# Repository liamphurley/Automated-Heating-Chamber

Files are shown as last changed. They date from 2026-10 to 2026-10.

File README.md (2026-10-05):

# ESP32 Automated Heating Chamber

An ESP32-based temperature control system that monitors temperature with a **DS18B20 digital temperature sensor**, controls a **12 V heating element and cooling fan**, displays live information on an **OLED screen**, and provides a **Wi-Fi web interface** for remote temperature control and monitoring.

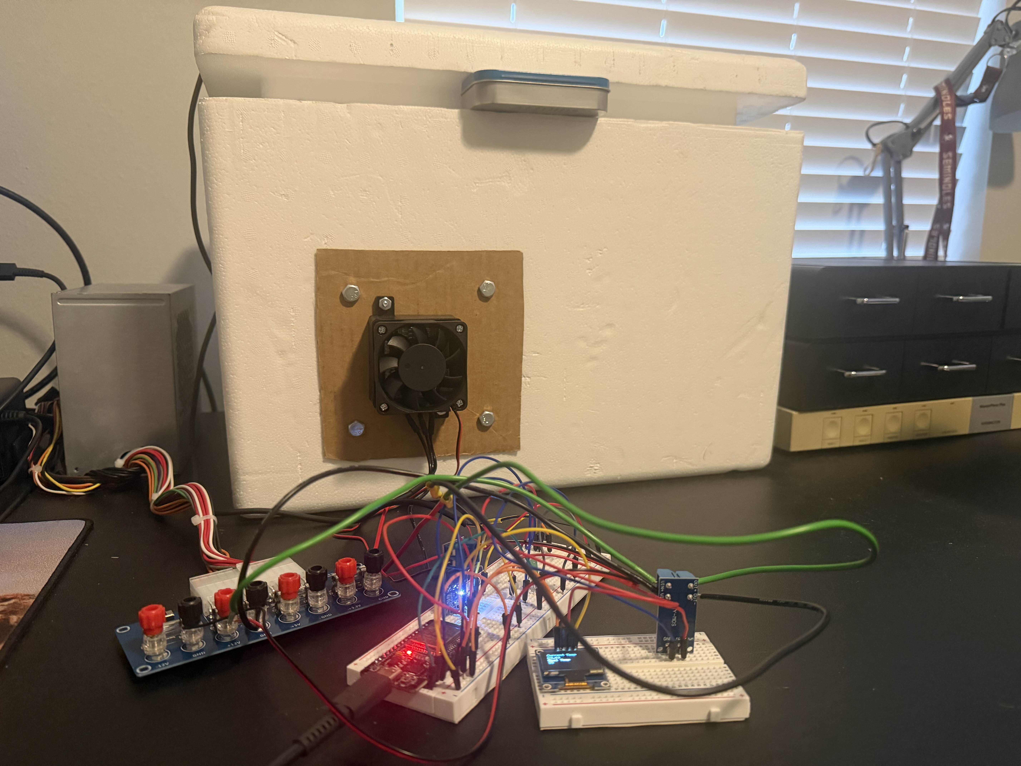
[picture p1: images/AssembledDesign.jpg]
Assembled Design


## Features

*  Real-time temperature measurement using a DS18B20
*  Automatic heating control based on a configurable target temperature
*  Cooling fan control
*  128×64 SSD1306 OLED display
*  Wi-Fi connectivity through the ESP32
*  Browser-based control interface
*  Temperature history logging
*  Text-based temperature graph accessible through the web interface
*  Stores up to 5,000 temperature records in memory
*  Records temperature and heater state over time

## Hardware

| Component | Purpose | ESP32 Pin |
| --- | --- | ---: |
| ESP32 | Main controller | — |
| DS18B20 | Temperature sensor  | GPIO 2 |
| Heating element / MOSFET | Temperature control | GPIO 5 |
| Cooling fan / MOSFET | Cooling | GPIO 19 |
| SSD1306 OLED | Local display | I²C |
| 12 V power supply | Heater/fan power | — |

> **Note:** The heater and fan should not be powered directly from ESP32 GPIO pins. A suitable MOSFET or switching module must be used to interface the ESP32 with higher-power loads.

## System Overview

The ESP32 continuously measures the temperature and compares it against the user-defined target temperature.

```text
                 ┌─────────────────┐
                 │     ESP32       │
                 │                 │
                 │ Temperature     │
                 │ Control Logic   │
                 └───────┬─────────┘
                         │
              ┌──────────┼──────────┐
              │          │          │
              ▼          ▼          ▼
         DS18B20       Heater       Fan
        Temperature    Control     Control
          Sensor       GPIO 5     GPIO 19
              │
              │
              ▼
        Temperature Data
              │
        ┌─────┴─────┐
        │           │
        ▼           ▼
    OLED Display  Web Interface
```

## The Chamber

The Chamber was assembled using a stytofoam cooler with the heating component mounted to the side. The external bracket was made with cardboard due to a previous version's 3D printed PLA bracket melting while testing. Internally a 3D printed PLA bracket is still in use. The sensor is hanging in the center of the chamber while the lid is propped open for ventilation. 

The microcontroller, MOSFET boards, and OLED are all connected using breadboards and jumper wires. In a future version it would be best to clean up this assembly but, usability is fully intact due to the webpage. The power for the design is provided by a an ATX power supply connected to a fused adapter board.

Assembled Design

## Temperature Control

The system uses a target temperature (`goalTemp`) to determine when heating should be enabled or disabled.

The default target temperature is:

```cpp
int goalTemp = 35;
```

### Heating

When the measured temperature falls more than **0.5°C below the target**, the heater is enabled.

```text
Temperature < Target - 0.5°C
            ↓
        Heater ON
```

### Cooling

When the measured temperature exceeds the target temperature:

```text
Temperature > Target
            ↓
        Heater OFF
        Fan ON
```

The control logic also uses timing intervals to prevent the heater from being switched unnecessarily frequently.

## OLED Display

The SSD1306 OLED displays:

* Current temperature
* Target temperature

Example:

```text
Current Temp
34.72

Goal Temp
35
```

The display uses the Adafruit SSD1306 and Adafruit GFX libraries.

## Wi-Fi Web Interface

The ESP32 connects to a Wi-Fi network and starts an HTTP server on port `80`.

After connecting, the ESP32 prints its local IP address to the Serial Monitor.

```text
WiFi connected!
192.168.x.x
```

The IP address can then be entered into a browser on the same network.

### Web Interface

The web interface displays:

* Current temperature
* Current target temperature
* Temperature input field
* Temperature history graph

The target temperature can be changed directly from the browser.

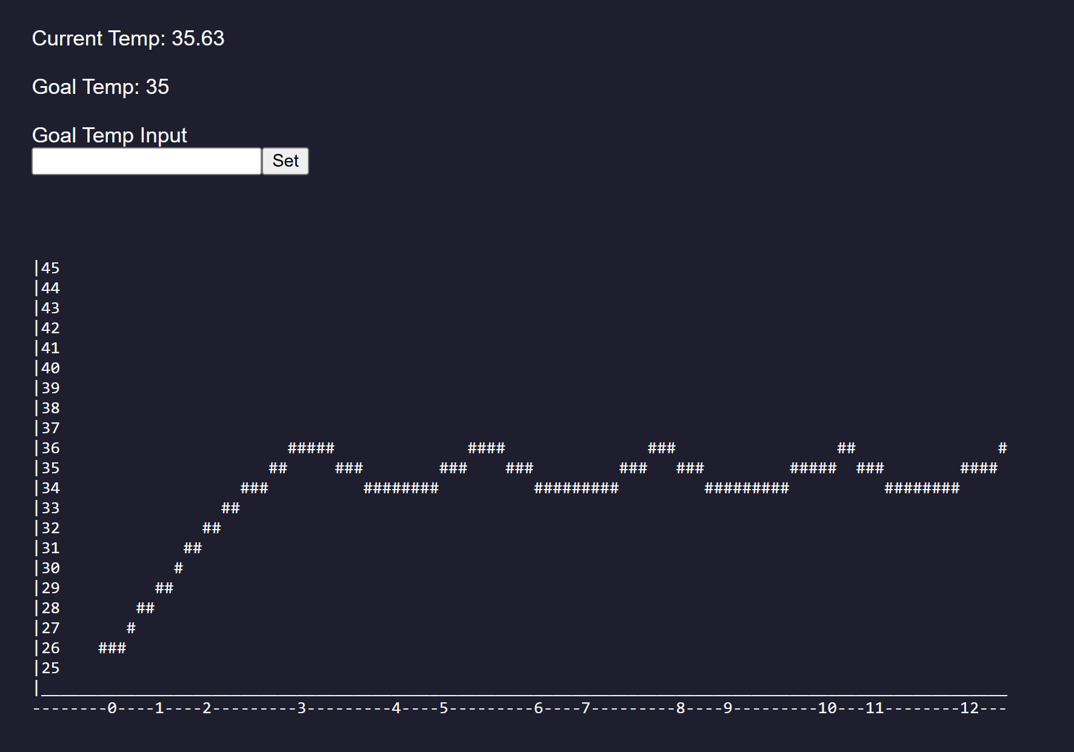
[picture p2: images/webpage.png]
Complete Webpage


## Temperature Logging

Temperature measurements are stored using the following structure:

```cpp
struct TemperatureRecord {
    unsigned long time;
    float temperature;
    bool heaterOn;
};
```

Each record contains:

| Field | Description |
| --- | --- |
| `time` | Milliseconds since ESP32 startup |
| `temperature` | Recorded temperature in °C |
| `heaterOn` | Heater state when the measurement was taken |

The system can store up to:

```cpp
#define RECORDS 5000
```

records.

Measurements are currently recorded approximately every **500 ms**.

## Temperature Graph

The `setGraph()` function converts the recorded temperature data into a text-based graph that can be displayed in the web interface.

For shorter recordings, individual temperature measurements are plotted.

For longer recordings, the data is grouped into approximately **100 sections**, with the temperature values averaged within each section. This allows the graph to represent longer recording periods without requiring thousands of characters.

The graph also includes:

* Temperature scale
* Target-temperature reference
* Time axis
* Temperature history

## Software

### Platform

* **Microcontroller:** ESP32
* **Framework:** Arduino
* **Language:** C++
* **Development Environment:** PlatformIO / Arduino-compatible environment

### Libraries

The project uses:

```cpp
#include <Arduino.h>
#include <OneWire.h>
#include <DallasTemperature.h>
#include <Adafruit_GFX.h>
#include <Adafruit_SSD1306.h>
#include <WiFi.h>
#include <WebServer.h>
```

| Library | Purpose |
| --- | --- |
| Arduino | Core ESP32 functionality |
| OneWire | Communication with the DS18B20 |
| DallasTemperature | Temperature sensor interface |
| Adafruit GFX | Graphics support |
| Adafruit SSD1306  | OLED display control |
| WiFi | ESP32 wireless networking |
| WebServer | HTTP server and web interface  |

## Pin Configuration

The primary GPIO assignments are defined at the beginning of the program:

```cpp
#define ONE_WIRE_BUS 2
#define heatPin 5
#define fanPin 19
```

### GPIO 2 — DS18B20

Digital OneWire communication with the temperature sensor.

### GPIO 5 — Heater

Controls the switching device connected to the heating element.

### GPIO 19 — Fan

Controls the switching device connected to the cooling fan.

## Configuration

The target temperature can be changed in the source code:

```cpp
int goalTemp = 35;
```

The Wi-Fi credentials are also configured in the source:

```cpp
const char* ssid = "YOUR_WIFI_NAME";
const char* password = "YOUR_WIFI_PASSWORD";
```

## Memory Considerations

The temperature history uses a statically allocated array:

```cpp
TemperatureRecord recArray[RECORDS];
```

With 5,000 records, this consumes a significant amount of the ESP32's available RAM.

Increasing `RECORDS` substantially may therefore require optimizing the record structure or using external storage.

## Project Architecture

The program can be divided into four primary systems:

### 1. Sensor System

```text
DS18B20
   ↓
DallasTemperature
   ↓
Temperature Reading
```

### 2. Control System

```text
Temperature
     ↓
Compare with Goal
     ↓
┌────┴────┐
↓         ↓
Heater    Fan
```

### 3. Display System

```text
Temperature + Goal
        ↓
   SSD1306 OLED
```

### 4. Network System

```text
ESP32
  ↓
Wi-Fi
  ↓
HTTP Web Server
  ↓
Web Browser
```

## Future Improvements

Potential improvements to the project include:

* [ ] Add humidity monitoring
* [ ] Add humidity control
* [ ] Add persistent data storage
* [ ] Improve graph scaling and resolution
* [ ] Add heater/fan status to the OLED
* [ ] Add configurable heating and cooling hysteresis
* [ ] Add maximum-temperature safety shutdown
* [ ] Add sensor-disconnection detection
* [ ] Add automatic Wi-Fi reconnection
* [ ] Move Wi-Fi credentials to a secure configuration file
* [ ] Add PWM control for more precise heating
* [ ] Add session-based data logging
* [ ] Add downloadable temperature data
* [ ] Improve the web interface with JavaScript-based live updates

## Safety

This project controls potentially high-power electrical loads. The ESP32 should **not** directly power a high-current heater or fan.

Use appropriately rated:

* MOSFETs or switching modules
* Power supplies
* Wiring
* Connectors
* Fuses
* Heat sinks
* Ground connections

The heating system should also include an independent safety mechanism capable of shutting down the heater if the ESP32, temperature sensor, or control software fails.

## Lessons Learned

It's important to define a specific scope for a project before beginning so a plan can be devised. Not doing this led to delays in this project that could have been avoided. Also a specific deadline could enable realistic goals.

## License

This project is intended for educational and personal engineering development.

If this repository is intended to be reused or modified by others, add an appropriate open-source license such as MIT before publishing.

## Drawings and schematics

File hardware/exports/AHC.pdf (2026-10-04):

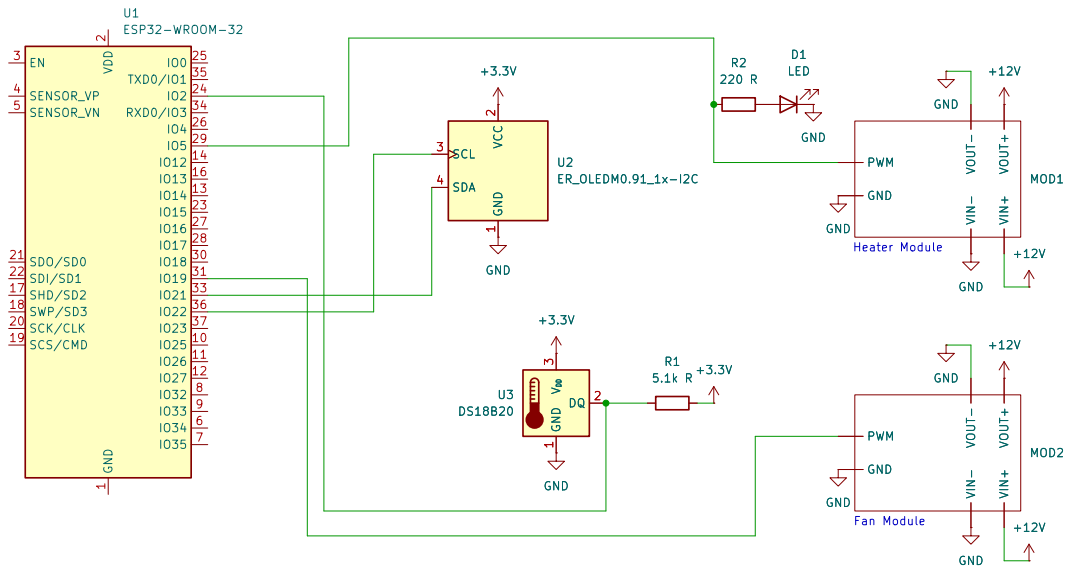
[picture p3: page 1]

Sheet: /
File: AHC.kicad_sch
Title: Automated-Heating-Chamber

Size: A4 | Rev:
KiCad E.D.A. 10.0.6 | Id: 1/1

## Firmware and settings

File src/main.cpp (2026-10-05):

#include <Arduino.h>
#include <OneWire.h>
#include <DallasTemperature.h>
#include <Adafruit_GFX.h>
#include <Adafruit_SSD1306.h>
#include <WiFi.h>
#include <WebServer.h>
#include <wificredentials.h>

#define ONE_WIRE_BUS 2  // GPIO connected to the DS18B20 data pin

#define heatPin 5

#define fanPin 19

OneWire oneWire(ONE_WIRE_BUS);
DallasTemperature sensors(&oneWire);

int goalTemp = 35;

unsigned long lastHeatUpdate =0;
unsigned long lastRecordUpdate=0;

#define SCREEN_WIDTH 128
#define SCREEN_HEIGHT 64

#define OLED_RESET -1

#define RECORDS 5000
int recordCount =0;
struct TemperatureRecord {
    unsigned long time;
    float temperature;
    bool heaterOn;
};
TemperatureRecord recArray[RECORDS];

Adafruit_SSD1306 display(SCREEN_WIDTH, SCREEN_HEIGHT, &Wire, OLED_RESET);

WebServer server(80);
const char* ssid = WIFI_SSID;
const char* password = WIFI_PASSWORD;

String graph ="";

String setGraph(TemperatureRecord arr[]);

float lastValidTemp = 0;

int invalidCount = 0;
bool error = 0;

void setup() {
    Serial.begin(115200);
    sensors.begin();

    //Pin Setup
    pinMode(heatPin, OUTPUT);
    pinMode(fanPin, OUTPUT);

    // Start the OLED display
    if (!display.begin(SSD1306_SWITCHCAPVCC, 0x3C)) {
      while (true); // Stop if display isn't found
    }

    // Display text OLED
    display.setTextSize(1);
    display.setTextColor(SSD1306_WHITE);
    display.setCursor(10, 5);

    //Server
      // Connect to Wi-Fi
    
    Serial.print("Connecting to WiFi");
                                          
    WiFi.begin(ssid, password);

    while (WiFi.status() != WL_CONNECTED) {
      delay(500);
      Serial.print(".");

    }
    Serial.println("\nWiFi connected!");
    Serial.println(WiFi.localIP());

    server.on("/", []() {

    graph = setGraph(recArray);

    String webpage = "<html><head><style>body { background-color: #1e1e2e; color: #f5f5f5; font-family: sans-serif; padding: 20px; }</style></head><body>Current Temp: " + String(sensors.getTempCByIndex(0));
    webpage += "<br><br>Goal Temp: " + String(goalTemp) + "<br><br> Goal Temp Input";

    webpage += "<form action='/set'>";
    webpage += "<input name='temp' type='number'>";
    webpage += "<input type='submit' value='Set'>";
    webpage += "</form><br><pre>" + graph + "</pre>";

    server.send(200, "text/html", webpage);
    });

    server.on("/set", []() {
    goalTemp = server.arg("temp").toInt();
    server.sendHeader("Location", "/");
    server.send(303);
    });

    server.begin();

    display.clearDisplay();

  }

void loop() {
    
    sensors.requestTemperatures();

    float tempC = sensors.getTempCByIndex(0);

    if ((tempC<goalTemp-0.5)&&(tempC>-120)&&!error)
    {
      if(millis() - lastHeatUpdate >= 5000)
      {
        digitalWrite(heatPin, HIGH);
        lastHeatUpdate=millis();
        digitalWrite(fanPin, HIGH);
        invalidCount = 0;
      }
    } else if((goalTemp<tempC)&&(tempC>-120)&&!error)
    {
      if(millis() - lastHeatUpdate >= 500)
      {
        digitalWrite(heatPin, LOW);
        lastHeatUpdate=millis();
        digitalWrite(fanPin, HIGH);
        invalidCount = 0;
      }
    }else 
    {
      ++invalidCount;
      if(invalidCount>50)
      {
        digitalWrite(heatPin, LOW);
        digitalWrite(fanPin, LOW);
        error = 1;
      }
    }

    if ((recordCount <RECORDS)&&(millis()-lastRecordUpdate)>=500)
    {
      recArray[recordCount].time = millis();

      if(tempC>-120)
      {
        recArray[recordCount].temperature = tempC;
        lastValidTemp = tempC;
      }else{
        recArray[recordCount].temperature = lastValidTemp;
      }
      recArray[recordCount].heaterOn = digitalRead(heatPin);

      lastRecordUpdate = millis();

      recordCount++;
    }


  
    display.clearDisplay();
    display.setCursor(10,5);
    display.print("Current Temp");
    display.setCursor(10,15);
    display.print(tempC);
    display.setCursor(10,25);
    display.print("Goal Temp");
    display.setCursor(10,35);
    display.print(goalTemp);
    display.display();
 
    server.handleClient();
}


String setGraph(TemperatureRecord arr[]) {

  const int columns = 102;
  int rows = 20+2;

  String graph = " ";
  String finalXaxis ="";
  String chunkXaxis ="";

  float plotable[columns - 2];
  float plotSum=0;
  int targetRow;

  if(recordCount>(columns-2))
  {
    for(int i=0 ; i<(columns-2); ++i)
      {for (int j=(i*(recordCount/(columns-2))) ; j<(recordCount/(columns-2))+(i*(recordCount/(columns-2))); ++j)
        {
          plotSum += arr[j].temperature;
        }
      plotable[i]=plotSum/(recordCount/(columns-2));
      plotSum=0;
    }
  }

  for (int i = 0; i < rows; i++) {
    for (int j = 0; j < columns; j++) {

      if(j!=80&&j!=81)

      if(!(recordCount>(columns-2)))
        {targetRow = 20 - ((int)round(arr[j].temperature - (goalTemp - ((rows-2)/2)) - 1));
        }else{
          targetRow = 20 - ((int)round(plotable[j] - (goalTemp - ((rows-2)/2)) - 1));
        }

      if (j == columns - 1) {
        graph += '\n';  // Add newline at end of row
        graph += "|";
        if(i < rows-1)
        {
          graph += goalTemp+((rows-2)/2)-i;
        }
      } else if(i < rows-1){
        if(targetRow==i)
        {
          graph+="#";
        }else{
          graph+=" ";
        }
      }
    }
  }

  for(int i=0 ; i<columns; ++i)
  {
    graph += "_";
  }

  unsigned long Xaxis[columns - 2];
  int lastDigit = 1000000;
  int characterCount =6;

  if(recordCount>(columns-2))
  {
    for(int i=0 ; i<(columns-2); ++i)
      {for (int j=(i*(recordCount/(columns-2))) ; j<(recordCount/(columns-2))+(i*(recordCount/(columns-2))); ++j)
        {
          plotSum += arr[j].time;
        }
      Xaxis[i]=plotSum/(recordCount/(columns-2));
      plotSum=0;
    }
    for(int i=-5 ; i<(columns-2); ++i)
    {
      if(i>2)
      {
        if(i%5==0)
        {

            if(lastDigit == Xaxis[i]/60000)
            {
              finalXaxis += "-----";
            }else{
              finalXaxis += Xaxis[i]/60000;
              
              if(Xaxis[i]/60000<10)
              {
                finalXaxis += "----";
              }else if(Xaxis[i]/60000<100)
              {
                finalXaxis += "---";
              }else if(Xaxis[i]/60000<1000)
              {
                finalXaxis += "--";
              }
              lastDigit = Xaxis[i]/60000;
            }
        }else{
          //finalXaxis += ' ';
        }
      }else{
        finalXaxis += '-';
      }
    }
  }
  

  graph += '\n';
  graph += finalXaxis;

  if(error)
  {
    graph = "Sensor Read Error";
  }

  return graph;
}
